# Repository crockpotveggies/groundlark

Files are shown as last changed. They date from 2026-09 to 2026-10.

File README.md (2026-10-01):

Groundlark — lark and seismic waveform

# Groundlark — open hardware for seismic and environmental monitoring

Groundlark is a family of hardware boards and companion software for seismic
and environmental monitoring. Each board has its own hardware directory, with
shared component libraries, interfaces and validation tools.

The family has **three products**: the Groundlark FPGA HAT, Skylark and
Burrowlark USB sensor heads. All share the sensor contracts, simulation tools and local workbench.

## Groundlark

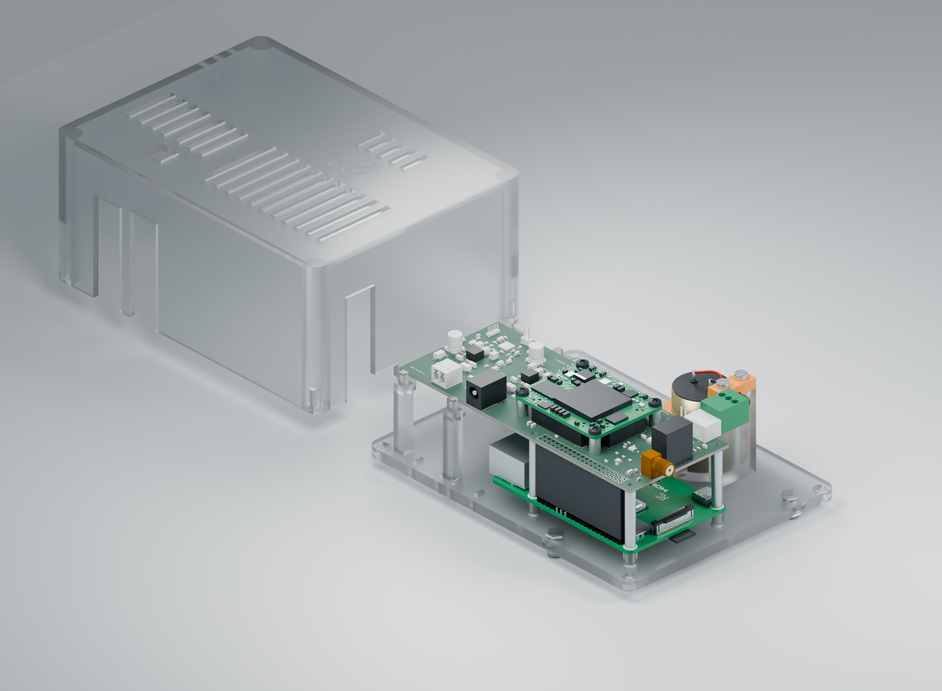
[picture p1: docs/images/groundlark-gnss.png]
Groundlark revised power and GNSS circuit: routed HAT with antenna current limiting, side SMA, Pi/Trenz stack and geophone


**Seismic monitoring on a Raspberry Pi.** The active
[Groundlark FPGA HAT](hw/groundlark-fpga-hat/README.md), model **DAQHAT-01**, is a
140 × 56 mm, six-layer FR-4 board with three XYZ LSM6DSO IMUs and an ADS122C04
input for an external Racotech geophone, plus a fitted DLVR infrasound sensor and u-blox MAX-M10S GNSS with a side-facing SMA antenna connector. The stack is **Pi → HAT → Trenz
Artix-7 200T FPGA**. Pi acquisition works independently of a configured FPGA.

The [internal FPGA link](docs/fpga-host-link.md) provides six QSPI wires, UART,
reset and switched Pi-driven JTAG. An SPI echo bitstream is implemented;
accelerated sensor processing and native quad transfers remain future work.
The FPGA uses a separate Nexys Video-compatible 12 V, center-positive adapter through J83 and an onboard 3.326 V converter. See the [power limits](docs/trenz-hat.md).

**Status:** active prototype. Physical power, fit, timing, noise and thermal
qualification remain pending. See the [stack assembly guide](docs/stack-assembly.md),
[JLCPCB instructions](docs/jlcpcb-assembly.md) and [bench procedure](docs/bench-procedure.md).
The JLCPCB package targets one assembled HAT; sourcing, placement and J1 fit
checks remain open. Fabrication packages stay local in ignored `hw/releases/`.

*R3 [prototype enclosure](hw/mechanical/daqhat-01-case/README.md), current
140 mm HAT CAD with GNSS/SMA, infrasound, TI Pi supervision and independent FPGA power, vendor Trenz components and a detailed
[Pi 4B model](hw/shared/models/raspberrypi4/README.md) by integrated-circuit / FreeCAD
community (CC BY 3.0). Clear PETG appearance, risers, geophone and wiring are approximate.
Physical fit remains unqualified. [Render provenance](docs/images/groundlark-gnss.json).*

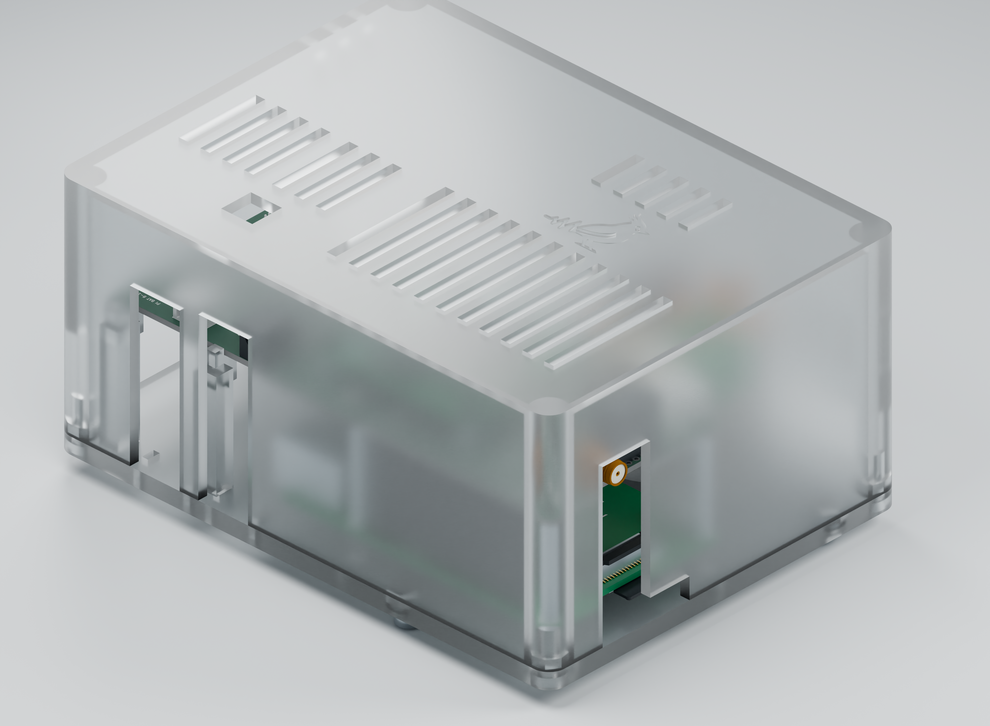
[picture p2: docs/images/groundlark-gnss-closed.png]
Groundlark enclosure with the side SMA accessible


[Closed enclosure render provenance](docs/images/groundlark-gnss-closed.json).
Measured gain/offset workflows and PCB probe access are in the
[calibration guide](docs/calibration.md). Seismic recordings support local
[miniSEED export](docs/miniseed.md).

## Skylark

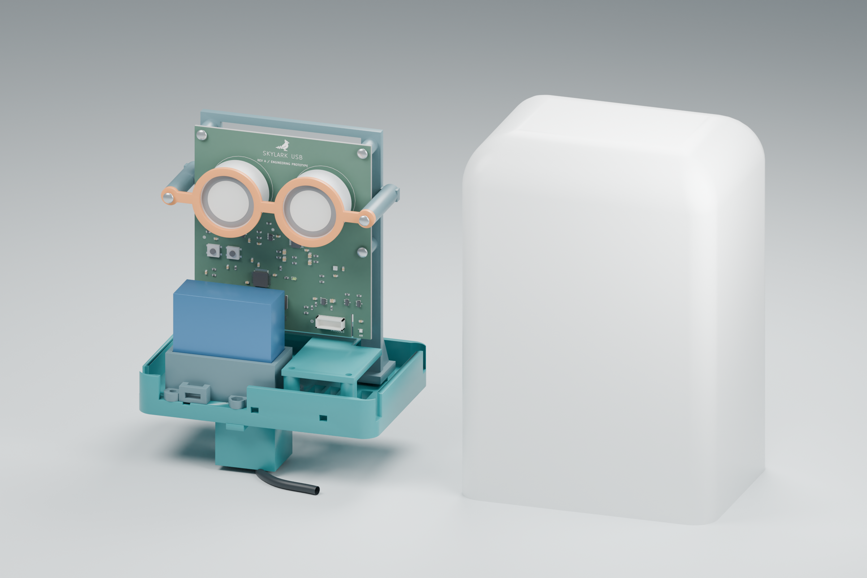
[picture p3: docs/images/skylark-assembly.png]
Skylark USB: populated vertical PCB and gas cells in the removable tray, with the white bell enclosure beside it


**Outdoor air-quality monitoring over USB.** [Skylark USB](hw/skylark-usb/README.md)
combines a vertical **90 × 100 mm PCB** with a removable sensor tray and a
**130 × 94 × 185 mm bell enclosure**.

- **Particles:** Plantower PMS5003, with separate downward-facing inlet and exhaust paths.
- **Gases:** socketed SGX-7SO2-AQ-20 sulfur dioxide and SGX-7H2S-AQ-25 hydrogen sulfide cells.
- **Weather:** SHT40 temperature/humidity and BMP390 barometric pressure.
- **Connection:** USB-C power and data through an STM32F072 microcontroller.
- **Housing:** printable bell, rear M4 keyhole mounts and a removable tray with
  separate PMS cradle and splash cover. Bottom ventilation is sheltered by a 25 mm skirt.

[Prototype firmware](sw/skylark/README.md) implements sensor acquisition and
USB streaming. The shared workbench includes Skylark simulation, recording/replay,
board-specific tests and an interactive 3D PCB. Gas data retains separate raw
working and auxiliary electrode counts; concentrations require calibration.

**Status:** Rev A PCB, Rev G enclosure and prototype firmware are implemented.
Physical fit, USB power behavior, analog performance, gas response and weather
resistance still require qualification. The ventilated enclosure has no assigned
IP rating. Follow the [PCB guide](hw/skylark-usb/README.md) and
[enclosure assembly instructions](hw/skylark-usb/mechanical/bell/README.md).

*Render: native PCB artwork and authored component models in the CAD-derived
tray, with the bell set beside it. Component bodies are dimension envelopes;
fasteners and cable dressing are illustrative. [Render provenance](docs/images/skylark-assembly.json).*

## Burrowlark

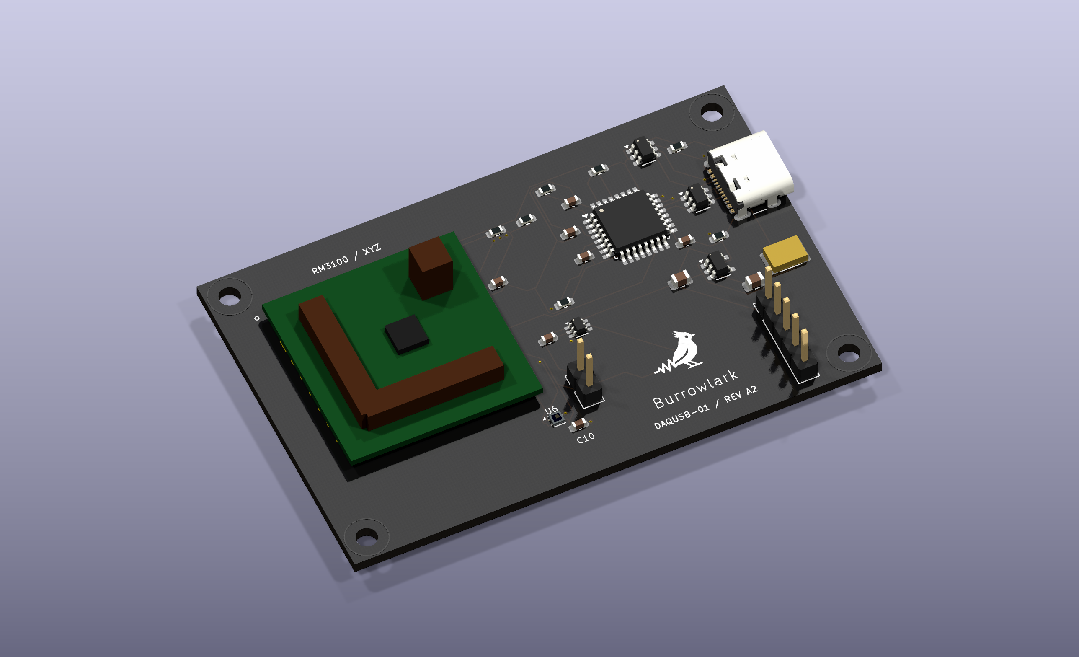
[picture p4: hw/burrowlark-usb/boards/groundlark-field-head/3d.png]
Burrowlark DAQUSB-01 Rev A2: USB-C PCB with PNI RM3100 XYZ magnetometer and SHT45 temperature/humidity


**Remote magnetic and enclosure-climate sensing over USB.**
[Burrowlark USB](hw/burrowlark-usb/README.md), model **DAQUSB-01**, carries an
RM3100 magnetometer and SHT45 temperature/humidity sensor. It connects to the Pi through USB-C for power and data.
The DLVR infrasound sensor is fitted on Groundlark DAQHAT-01.

**Status:** hardware design and workbench simulation are present; MCU firmware
and physical qualification remain pending. See the
[USB sensor-head guide](docs/usb-sensor-head.md) for interfaces and assembly details.

*Render: native 70 × 45 mm PCB with favicon, Burrowlark name and DAQUSB-01 / REV A2
silkscreen, RM3100 module and SHT45 U6/C10; the former infrasound
footprint and bypass capacitor are removed. Module, fuse and SHT45 bodies are simplified
dimensional envelopes. [Render provenance](hw/burrowlark-usb/boards/groundlark-field-head/render-provenance.json).*

## Sensor workbench

The dark-mode Python UI lets you switch between Groundlark, Skylark and
Burrowlark, with interactive 3D views, raw-data charts, stimulus/fault controls,
board-specific tests and recording/replay.
No hardware or Docker is required. Follow the
[beginner walkthrough](docs/sensor-workbench.md) to create your first signal.

```powershell
# Windows: set up once, then launch
./setup-ui.ps1 -Check
./ui.ps1
```

On Linux/macOS, use `sh ./setup-ui.sh --check`, then `sh ./ui.sh`.
Open **http://127.0.0.1:8080**. Tools and dependencies stay in ignored `.local/`.

Groundlark sensor workbench showing the external geophone and a simulated 2 Hz signal

This is an actual browser screenshot with simulated data. Select the geophone
can or its HAT input to highlight both and inspect the same ADC stream.
Use the **Board** selector for the FPGA HAT, Burrowlark or Skylark.
**Test selected board** runs the selected board’s checks; the HAT test covers all
six sensors over eight simulated seconds. IMU, ADC and GNSS use production Pi
drivers on modeled buses; infrasound uses a raw-response model pending its Pi
driver. Signal checks and recordings/results are downloadable.
The Groundlark GNSS panel also models disconnected or shorted antennas, lock
loss and recovery, and PPS loss independently.
The UI simulates and replays; physical acquisition uses the [Pi software](docs/sensor-software.md).
Live seismic capture stores raw geophone and IMU counts locally as
[miniSEED 3](docs/miniseed.md), with SSREC companions for diagnostics and replay.

## Project files and tests

| Directory | Contents |
| --- | --- |
| [hw/](hw/README.md) | Four product directories, shared component resources, hardware checks and SPICE. |
| [sw/](sw/README.md) | Pi acquisition, contracts, simulator, FPGA and remote firmware interfaces. |
| [docs/](docs/README.md) | Setup, hardware specifications, assembly, interfaces and testing instructions. |
| [environment/](docs/portable-lab.md) | Pinned Docker test environment and bounded cleanup tooling. |

For the full test environment, run `./lab.ps1 build` once, then `./lab.ps1 test`.
Use `./lab.ps1 test -Profile software` for sensor contracts, acquisition,
recording/replay and recovery. See the [portable lab guide](docs/portable-lab.md)
for Linux commands, test scope, five-run retention and cleanup.

Hardware sources: [DAQHAT-01 circuit](hw/groundlark-fpga-hat/elec/hat_trenz.ato),
[KiCad PCB](hw/groundlark-fpga-hat/boards/groundlark-daqhat-01/groundlark-daqhat-01.kicad_pcb),
[Burrowlark DAQUSB-01](hw/burrowlark-usb/boards/groundlark-field-head/groundlark-field-head.kicad_pcb), and
[Skylark USB](hw/skylark-usb/boards/skylark-usb/skylark-usb.kicad_pcb).
See [build instructions](docs/build.md) and [source references](docs/sources.md).

## License

Project-authored code, hardware designs and documentation use the [MIT License](LICENSE).
Third-party assets and dependencies retain their own licenses and attribution.

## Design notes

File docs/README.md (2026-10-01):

# Documentation

## Getting started

- [Sensor workbench](sensor-workbench.md): installation, first experiment, recordings and replay.
- [Sensor software](sensor-software.md): command-line simulation and Pi acquisition.
- [Stimulus scenarios](stimulus-models.md): saved inputs, waveforms and sensor-model limits.
- [Project layout](project-layout.md): where to find hardware, software and generated files.

## Hardware and assembly

- [DAQHAT-01 hardware](trenz-hat.md): sensors, Trenz module, power, connectors and fabrication stack.
- [Pi/FPGA host link](fpga-host-link.md): SPI/QSPI pins, UART, JTAG and bring-up.
- [Geophone input](geophone-input.md): Racotech connection, analog circuit and accelerometer axes.
- [Sensor bandwidth and timing](sensor-response.md): Groundlark and Skylark attenuation, sampling and qualification limits.
- [Power supplies](power-supplies.md): Pi-header and USB allocations, source-voltage restrictions and startup/suspend requirements.
- [Stack assembly](stack-assembly.md): Pi, HAT, FPGA, cooling, supports and geophone lead.
- [JLCPCB assembly](jlcpcb-assembly.md): upload files, selected parts, placement and manufacturing requirements.
- [Physical bench procedure](bench-procedure.md): power, fit, timing and noise measurements.
- [Validation and release limits](validation.md).
- [Burrowlark DAQUSB-01 USB sensor head](usb-sensor-head.md): magnetometer and firmware interface.

## Interfaces and reproducible builds

- [Sensor data contract](sensor-contract.md) and [schema tools](../sw/interfaces/README.md).
- [GNSS hardware](gnss-hardware.md): MAX-M10S, side SMA, antenna and power requirements.
- [GNSS timing](utc-timing.md): BCM24 PPS capture, recording-bound UTC correlation and timing qualification.
- [Hardware build](build.md), [portable tests](portable-lab.md) and [SPICE scope](../hw/shared/simulation/README.md).
- [Component and vendor references](sources.md).

The hardware is an engineering prototype. Modeled tests do not replace physical
power, fit, timing, thermal or noise qualification.

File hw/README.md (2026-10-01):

# Hardware

Each product has its own directory. Existing model names and atopile targets
remain stable so board identity does not depend on its directory name.

| Product | Model / outline | Build target | Status |
| --- | --- | --- | --- |
| [Groundlark FPGA HAT](groundlark-fpga-hat/README.md) | DAQHAT-01, 140 × 56 mm | `trenz_hat` | Active prototype; physical qualification pending. |
| [Burrowlark USB](burrowlark-usb/README.md) | DAQUSB-01, 70 × 45 mm | `field_head` | Hardware design present; firmware pending. |
| [Skylark USB](skylark-usb/README.md) | Rev A, 90 × 100 mm | `skylark` | Routed air-quality prototype, STM32 firmware and Rev G bell enclosure; physical qualification pending. |

## Product contents

- `elec/`: authored circuit and product-specific part definitions.
- `layout/placement.json`: placement metadata for that board.
- `layout/<target>/`: atopile connectivity layout and local library tables.
- `boards/<board>/`: routed native CAD, review schematics, BOMs, previews and validation evidence.
- `mechanical/` and `simulation/`: product-specific artifacts where applicable.

Skylark includes its circuit, routed PCB, review schematic, BOM and CAD renders.
Stack concept boards are visualization artifacts.

## Shared resources and tooling

[shared/](shared/README.md) holds common part definitions, KiCad libraries, models,
vendor/reference material and simulations used by multiple boards. Custom CAD
resource paths remain relative.

`tools/` and `tests/` retain the existing shared and cross-board checks.
`assembly/<product>/` holds procurement overrides; `releases/<product>/` is for
ignored local fabrication packages, which require explicit authorization to publish.
Disposable runs belong in `.lab/`; local dependencies belong in `.local/`.
Firmware and host software belong in `sw/`.

`ato.yaml` defines four implemented targets. Direct atopile commands target
`hw/` from the repository root and write authoring outputs.

Use the root portable lab for routine checks. See the [build guide](../docs/build.md),
[Trenz guide](../docs/trenz-hat.md) and [validation limits](../docs/validation.md)
before invoking the lower-level authoring tools.

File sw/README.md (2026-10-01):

# Software

The sensor HAT is driven by Pi software; it does not need separate MCU firmware.
The [acquisition software](../docs/sensor-software.md) supports sensors on the
DAQHAT-01 FPGA stack and runs without a configured FPGA.
The sensor contracts and Pi acquisition application are executable:

- [interfaces/](interfaces/README.md): Protobuf schemas, semantic validation and bounded USB framing.
- [pi/](pi/README.md): Pi device configuration, sensor drivers/adapters, acquisition,
  calibration and timestamps.
- [field-head/](field-head/README.md): microcontroller firmware for Burrowlark
  (DAQUSB-01), the remote USB-C magnetometer board.
- [skylark/](skylark/README.md): buildable STM32 USB air-quality firmware, native driver fault tests and shared v1 capture.
- [fpga/](fpga/README.md): Trenz pin/connectivity qualification and minimal test
  bitstreams; accelerator implementation is deferred.
- [tests/](tests/README.md): portable replay, fault injection and host integration.
- [ui/](ui/README.md): Python/NiceGUI local sensor workbench, board explorer,
  stimulus controls and recording/replay.

Run `./lab.ps1 test -Profile software` after rebuilding the portable image.
This checks schemas, compatibility, acquisition/replay, modeled bus drivers,
USB streams and recovery from injected faults. See the
[software run guide](../docs/sensor-software.md). Burrowlark and Skylark prototype firmware have native C and ARM checks; physical qualification remains pending. Tests do not emulate
Pi/MCU instructions or enumerate a USB sensor head.

## Pi power policy

The optional TI supervisor has a disabled [configuration template](pi/deploy/power-policy.example.json)
and a tested [validator](pi/groundlark/power_config.py). Battery thresholds are
intentionally unset. [Prototype MSPM0 firmware](supervisor/README.md), validated
build-time policy generation and Pi kernel shutdown/acknowledgement configuration
are implemented. The default firmware keeps RUN off; loading the JSON template
does not change hardware power. Battery selection and physical qualification remain pending.
See the [power operating specification](../docs/power-supplies.md#pi-supervisor-and-battery-input).

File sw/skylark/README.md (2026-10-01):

# Skylark USB firmware

Prototype firmware for the **STM32F072CBT6** on the current Skylark Rev A PCB.
The ARM image builds and the production C sensor drivers, encoder and boot
journal run in native fault tests. Physical USB enumeration, suspend current,
sensor timing, analog settling and calibration still require a populated board.

## Build and test

From the repository root:

```powershell
./lab.ps1 build
./lab.ps1 unit
./lab.ps1 test -Profile software
```

Linux/macOS: use `sh ./lab.sh build`, `sh ./lab.sh unit`, and
`sh ./lab.sh test --profile software`. The shared software profile builds the
firmware, checks wire compatibility, and compiles/runs the actual C drivers with
injected I²C/UART failures. It also exercises queue overflow, reconnects, warmup,
conversion-counter loss, and interrupted flash writes/erases.

The lab uses Debian ARM GCC 12.2.1 and libopencm3 commit
`2da12dc96e0b9e42a3332348dd9b02a0a17981f8`, fetched and SHA-256 verified by
[install_skylark.py](../../environment/install_skylark.py). Complete upstream
sources and licenses remain under `/opt/skylark/libopencm3` in the image.
The application is MIT; libopencm3 retains its LGPL-3.0-or-later license.
Preserve corresponding sources and license notices when distributing firmware.

For a direct Linux build with that library and an ARM GCC toolchain:

```sh
make -C sw/skylark/firmware LIBOPENCM3=/absolute/path/to/libopencm3 \
  EXTRA_CFLAGS=-isystem/usr/include/newlib
```

Outputs are ignored `sw/skylark/build/skylark.elf` and `skylark.bin`.
The portable profile instead builds under `sw/build/skylark-arm/` in its
disposable workspace and retains ELF/BIN/map plus size and SHA-256 metadata in
`.lab/runs/<run-id>/results/sw/build/skylark-arm/`. The link reserves at least 4 KiB for stack; no heap or
RTOS is used. Physical stack watermarking remains part of bring-up.

## Program a prototype

Use J3 SWD with a 3.3 V compatible ST-Link and the STM32F0 target profile.
The image starts at `0x08000000`; the last **4 KiB at 0x0801F000–0x0801FFFF**
store a two-page boot counter. Program/verify only image pages. **Do not mass
erase or overwrite the journal during updates:** reusing a device/boot identity
breaks recording ordering. A failed or exhausted counter stops acquisition.
SW1 resets the MCU; SW2 selects the STM32 ROM bootloader when held during reset.
The normal acquisition path needs neither button.

Default USB **1209:0001** is the pid.codes identifier reserved for
[private in-house testing](https://pid.codes/1209/0001/). Before distributing
devices, build with an allocated VID/PID via
`EXTRA_CFLAGS='-DSK_USB_VID=... -DSK_USB_PID=... -isystem/usr/include/newlib'`.
The serial string is the MCU's 96-bit unique ID. The USB device requests 500 mA.

## Acquisition

USB configuration starts sensor power and acquisition. CDC DTR opens the data
session; closing the port leaves the cells conditioned and continues acquisition
without buffering disconnected samples. Reopening announces a new configuration
revision with sequence continuity and does not restart conditioning.
USB reset, unconfiguration or suspend clamps the electrodes and removes
analog/PMS power. Restoring USB power authorization repeats sensor setup and warmup.
The MCU reduces its clock to 12 MHz in suspend and disables the ADC/UART/I²C peripherals;
the actual total suspend current and USB compliance are **not measured**.

| Sensor | Firmware behavior |
| --- | --- |
| ADS122C04, I²C 0x40 | AIN0/1 = SO₂ working/auxiliary; AIN2/3 = H₂S working/auxiliary. Gain 1, PGA bypass, external 2.5 V reference, normal 330 SPS single-shot conversions. Four slots, 8 ms apart; 32 ms per channel. Readback, inverted-data integrity and conversion counter checked. |
| SHT40, I²C 0x44 | Serial probe, high-precision measurement approximately every second, CRC on both raw words; heater off. Conversion waits are nonblocking. |
| BMP388, I²C 0x76 | Chip ID 0x50/readback, pressure ×8 and temperature ×2 oversampling, 3.125 Hz normal mode; latest ready sample every second. Six raw bytes plus 21 factory trim bytes retained. |
| PMS5003, USART2 | 9600 8N1; complete 32-byte active-mode frames with checksum/error-byte checking. Latest fresh frame published every second. Rail-fault/low-VBUS detection disables power. |

On startup, analog rails settle for 150 ms while electrodes remain clamped.
Gas samples are **missing for 60 seconds**, PMS samples for **30 seconds**.
These are prototype policies, not measured cell stabilization guarantees.
Keep raw working and auxiliary values separate. ADC volts = counts × 2.5 / 2²³;
ppm conversion, zero/temperature compensation and detection thresholds require
cell-specific calibration, polarity checks and environmental qualification.

The gas ADC scheduler advances one channel per completed service slot. A delayed
loop extends the schedule and exposes sequence gaps; it cannot start a burst of
conversions without waiting for them. Each new conversion receives at least
five integer-millisecond ticks after START, exceeding the 3.13 ms slow-clock conversion time. The 8 ms schedule includes I²C transfer time. This does not make WE/AE simultaneous. See
[sensor bandwidth and timing](../../docs/sensor-response.md) for attenuation,
aliasing and the remaining physical response limits.

Three I/O failures latch the affected sensor until USB power is reset. Closing
and reopening the serial port does not clear the latch or disturb electrode bias.
All four gas streams share the ADC's fault state; other sensors continue.
Not-ready, invalid checksum, stale PMS data, warmup and unknown conversion loss
never become zero measurements. The eight-frame transmit queue drops newest
data under backpressure. Sequence gaps remain visible; loss counts are unknown.
The firmware never resets the ADC solely because its counter skipped.

The MCU supply-monitor ADC has bounded calibration, enable, conversion and
disable waits. Calibration includes the ES0223 settling workaround. Timeout or
overrun disables the monitor until re-enabled; an unavailable monitor prevents
PMS power authorization. A late result cannot be reused as a different channel.
The I²C master clears spurious BERR as specified by ES0223, while NACK and
arbitration loss remain failures even when a completion flag is also set.
The bus remains at 100 kHz with an 8 MHz kernel clock. USB/APB remains at
least 12 MHz during suspend polling and resume. Unconnected MCU pins have
their digital input buffers disabled. See [source budgets](../../docs/power-supplies.md)
for supply-voltage restrictions and the unmeasured suspend-current requirement.

## Capture and replay

The firmware uses the existing [v1 sensor contract](../../docs/sensor-contract.md):
COBS, CRC-32, protobuf identity/configuration/batches/status, board ID 3.
No ASCII console, command protocol or calibrated gas values are emitted.
Generate the current descriptor as described in the
[software guide](../../docs/sensor-software.md), then on Linux:

```sh
python sw/tools/sensor.py usb --board skylark --usb /dev/ttyACM0 \
  --seconds 120 --output sw/build/skylark-field.ssrec
python sw/tools/sensor.py replay sw/build/skylark-field.ssrec
python sw/tools/sensor.py simulate --board skylark --seconds 8 \
  --output sw/build/skylark-sim.ssrec
```

Prefer the actual `/dev/serial/by-id/...` path when several USB devices exist.
The same bounded receiver, validation and recording format serve both USB boards.
Open captures in the existing workbench; choose **Skylark USB** for simulation,
or **Test selected board** for an ideal-stimulus acquisition/replay check.
That UI test does not run MCU instructions. Native C driver tests and ARM linking
are in the portable software profile. Burrowlark firmware remains separate.

## Source references

- [TI ADS122C04 datasheet](https://www.ti.com/lit/ds/symlink/ads122c04.pdf), register map and data integrity.
- [Sensirion SHT4x datasheet](https://sensirion.com/resource/datasheet/sht4x), commands and CRC.
- [Bosch BMP388 datasheet](https://www.bosch-sensortec.com/media/boschsensortec/downloads/datasheets/bst-bmp388-ds001.pdf), register profile and compensation.
- [libopencm3](https://github.com/libopencm3/libopencm3), STM32 peripherals and USB CDC support.
- [STM32F072 ES0223](https://www.st.com/resource/en/errata_sheet/es0223-stm32f072x8xb-device-errata-stmicroelectronics.pdf), ADC calibration, I²C master BERR and USB/APB limits.
- [Hardware pin/power requirements](../../hw/skylark-usb/README.md), including the SGX bias assumption and outstanding physical checks.

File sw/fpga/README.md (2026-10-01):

# Trenz FPGA integration

DAQHAT-01 reserves six SPI/QSPI signals and retains UART/reset. Four data-link
wires switch to dedicated JTAG for programming directly from the Pi. See the
[host-link guide](../../docs/fpga-host-link.md) and
[pin contract](../../docs/trenz-gpio-breakout.csv).

The initial Pi 4 transport is ordinary SPI6, with DQ2/DQ3 unused. Quad needs a
separate host engine and reviewed slave RTL. Keep sensor acquisition independent
of FPGA configuration. An existing Nexys
Video bitstream is not a Trenz port.

`rtl/daqhat_01_link.sv` is a single-clock 50 MHz SPI echo mailbox with length/CRC/sequence
checks and one-frame backpressure. Run `python3 sw/fpga/test.py` with the pinned
Icarus installation, or use the full/software lab profile. `build.tcl` implements
it for XC7A200T-FBG484-1 in Vivado; run from ignored `.local/` storage. The
[recorded implementation evidence](verification/result.json) includes timing,
CDC, DRC and source hashes. Physical Pi/Trenz programming remains untested.

`cosim.py` connects the production Python client to simulated RTL pins, covering
all 193 payload sizes, sequence wrap, 20 clock phases and 491 malformed/reset cases.
`verify_reports.py` rejects stale source/report hashes, missing timing coverage,
negative slack and reported CDC/DRC findings. After a successful Vivado build,
record it with `python sw/fpga/verify_reports.py --record /path/to/output`, then
run the portable tests. The portable evidence check verifies those recorded
results; it does not run Vivado inside Docker.

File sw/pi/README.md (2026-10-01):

# Raspberry Pi software

Use `calibration-observe` and `calibration-fit` for measured static gain/offset. The [calibration guide](../../docs/calibration.md) covers fixtures, templates, evidence and instrument binding.

Executable acquisition, calibration, bounded recording/replay, Linux adapters
and deterministic simulation are in `groundlark/`. No configured FPGA is needed.
See the [run guide and recovery policy](../../docs/sensor-software.md).
Live HAT capture writes local [miniSEED 3 seismic files](../../docs/miniseed.md)
alongside SSREC diagnostics. Counts remain raw; Pi system timing is marked unverified.
Use the [stimulus guide](../../docs/stimulus-models.md) for motion/field/pressure
waveforms, GNSS trajectories and timed faults. Example: add
`--scenario sw/pi/profiles/stimulus-demo.json` to the simulation command.

Separate pure processing/protocol logic from Linux I2C/SPI/UART/USB adapters so
the same application can run against recorded samples and fault-injecting fakes.
Use the [DAQHAT-01 sensor/carrier design](../../docs/trenz-hat.md) and
[USB interface contract](../../docs/usb-sensor-head.md).

Run `./lab.ps1 test -Profile software` for the complete portable demo and tests.
Live adapters cover LSM6DSO, legacy SCL3300, ADS122C04, DLVR-F50D and MAX-M10S.
Bus logic has modeled-response tests. The geophone has a dedicated DRDY worker
with bounded buffering and explicit loss reporting.
[Pi 4 deployment](deploy/README.md), IRQ-assisted FIFO acquisition and PPS
edge recording are implemented. [UTC capture/correlation](../../docs/utc-timing.md)
and [bench report tools](../../docs/bench-procedure.md) are available; physical
timing bounds and validation remain bring-up work. USB ingestion expects a v1 producer;
both STM32 heads have prototype firmware with native fault tests and ARM builds.

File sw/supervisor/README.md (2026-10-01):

# DAQHAT-01 Pi power supervisor

`firmware/` targets MSPM0L1106TRHBR. The default image leaves RUN off because
the battery/controller policy is disabled. JP130 remains a bench override;
automatic operation requires removing its shunt.

The production C state machine checks voltage hysteresis, confirmation intervals,
minimum off time and halt acknowledgement. Invalid ADC readings request orderly
shutdown while running and prevent restart while off. Three shutdown timeouts
latch the controller off until reset. An independent watchdog resets a stalled
firmware loop. MCU reset returns RUN to its externally pulled-down state.

PA3 drives RUN, PA4 requests shutdown through Q130, PA5 reads ACK_N through Q131,
and PA27/ADC0.0 measures the R135/R136 divider. The nominal 2.5 V ADC conversion
is not calibrated. SWD remains available. The default image does not write factory
BCR/BSL configuration memory or provision a battery policy.

Build and native fault tests run in `./lab.ps1 test -Profile software`.
The TI SDK is pinned by `environment/install_supervisor.py`; its BSD notices
remain in the toolchain sources. Target linking and native tests are software
evidence only. ADC accuracy, voltage transients, watchdog timing and shutdown
behavior require the actual board.

For a later supervised bench build, start from
`sw/pi/deploy/power-policy.example.json`, select the protected battery/controller,
then generate a separate policy header:

```sh
python sw/supervisor/configure.py selected-policy.json /tmp/selected-policy.h
make -C sw/supervisor/firmware EXTRA_CFLAGS='-DPOLICY_HEADER=\"/tmp/selected-policy.h\"'
```

Every enabled policy must pass both the Python and C validators. Selecting a policy
does not qualify it. Flash over SWD only during physical bring-up.

Pi handshake settings are in `sw/pi/deploy/supervisor-boot.cfg`. BCM6 generates
a power-key shutdown request; BCM13 is asserted by the kernel poweroff path,
after filesystem shutdown. A stopped acquisition service never asserts halt.
Install the logind drop-in during that bring-up. The `gpio-poweroff` overlay
requires working external power removal; do not enable it with the default
disabled supervisor image or with JP130 bypassing the switch.

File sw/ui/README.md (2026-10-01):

# Python sensor workbench

From the repository root, run `./setup-ui.ps1 -Check`, then `./ui.ps1`.
On Linux/macOS, use `sh ./setup-ui.sh --check`, then `sh ./ui.sh`.
Open `http://127.0.0.1:8080`; Ctrl+C in the terminal stops the server.
See the [beginner walkthrough](../../docs/sensor-workbench.md).

The same app serves `/station` for persistent simulation or live acquisition.
Set the UI service's `GROUNDLARK_STATION_TOKEN` to match the local station service;
the browser never receives that API credential. Use the
[deployment guide](../pi/deploy/README.md) for station setup, storage, LAN login
and source profiles. Closing `/station` leaves capture running. Pause/resume,
completed-recording downloads and validated configuration editing are local.

Rerun `./ui.ps1 -Check` / `sh ./ui.sh --check` for the HTTP and scene tests.
The full acquisition/controller tests use the portable software profile.

- `main.py`: Python page construction, charts, board scene and user callbacks.
- `geophone_scene.py`: selectable external geophone and illustrative leads.
- `test_geophone_scene.py`: geometry and shared ADC/can selection regression.
- `test_skylark_scene.py`: exported cell dimensions, position and shared working/auxiliary selection.
- `style.css`: visual styling and responsive layout; dark by default.
- `pyproject.toml`, `uv.lock`: isolated, reproducible optional UI environment.
- `check.py`: page-construction/asset-delivery smoke check.
- `assets/`: checked display assets and provenance, separate from editable CAD.
- `build_wordmark.py`: compose the original favicon and outlined UI lettering
  for the shared README/header asset; see `assets/README.md` for regeneration.
- [workbench.py](../pi/groundlark/workbench.py): bounded framework-independent
  simulation/recording/replay controller.
- [test_workbench.py](../tests/test_workbench.py): controller regression tests.
- [hat_signals.py](../pi/groundlark/hat_signals.py): measured HAT signal regression
  behind the **Test selected board** button, using production drivers on modeled buses.

The UI is authored in Python. NiceGUI supplies bundled browser components based
on Vue, Quasar, Three.js and ECharts. There is no custom JavaScript application,
Node dependency install, npm build, or separate frontend server in this project.

The board selector switches experiments and models between the FPGA HAT,
Burrowlark and Skylark. `skylark_scene.py` adds
selectable gas/climate/PM targets to the native PCB/package GLB.
`build_skylark_model.py` is build-only tooling; its dependencies are separate
from the locked UI environment. See [asset provenance](assets/README.md).

Burrowlark includes RM3100 and SHT45 sensor 17. Select its enclosure-climate
channel to adjust temperature and humidity, inject faults and inspect both plots.
**Test selected board** verifies independent faults, recovery and recording/replay.
`build_burrowlark_model.py` merges the native KiCad export with the authored
PNI/PTC/SHT45 envelopes; see `assets/README.md` for regeneration.

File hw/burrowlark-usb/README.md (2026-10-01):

# Burrowlark USB — DAQUSB-01

Burrowlark is the separate 70 × 45 mm USB-C magnetometer and enclosure-climate
sensor head. It uses the PNI 14190 RM3100 XYZ module; U3/C5 and their pressure-sensor
branches are removed. The DLVR pressure sensor is on DAQHAT-01. Prototype
[USB-head firmware](../../sw/field-head/README.md) has native and ARM checks;
physical qualification remains pending.

Burrowlark DAQUSB-01 Rev A2 with favicon, RM3100 and SHT45

Native PCB render with the Groundlark favicon, Burrowlark name and
`DAQUSB-01 / REV A2` front silkscreen. The existing A2 board revision is retained.
Module, fuse and SHT45 bodies are simplified envelopes; see
[render provenance](boards/groundlark-field-head/render-provenance.json).

- [Electrical source](elec/field_head.ato)
- [Placement inputs](layout/placement.json)
- [Routed KiCad project](boards/groundlark-field-head/groundlark-field-head.kicad_pro)
- [Assembly and interface guide](../../docs/usb-sensor-head.md)
- [Firmware directory](../../sw/field-head/)

Build target: `field_head` in [hw/ato.yaml](../ato.yaml). Existing CAD filenames
and the DAQUSB-01 model identifier are preserved.

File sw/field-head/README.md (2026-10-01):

# Burrowlark DAQUSB-01 firmware

Prototype STM32F042K6 firmware implements RM3100 magnetic and SHT45
temperature/humidity acquisition, USB CDC framing and reconnect handshakes.
The authoritative interface is the existing
[Burrowlark circuit and firmware contract](../../docs/usb-sensor-head.md), with
messages and framing in the [sensor data contract](../../docs/sensor-contract.md).
The bounded encoder uses no heap. The ARM build reserves two 1 KiB boot-journal
pages and at least 2 KiB of stack; the shared software profile checks the link.

Actual enumeration, sensor behavior, USB suspend current and physical validation are pending.
This firmware is separate from the Pi software that drives the accelerometer HAT.

The SHT45 profile uses address 0x44, heater-off high precision (0xFD), a 9 ms
conversion wait and one six-byte CRC-checked raw frame per second. Publish
sensor 17 under the USB-head identity using MCU timing. The Python injected-bus
reference is `sw/pi/groundlark/burrowlark.py`; the browser simulation exercises
it. Native C tests independently decode the target encoder's output and inject
I2C failures, CRC faults, DTR reconnects, suspend and backpressure.

Run `./lab.ps1 test -Profile software` (or `./lab.sh test --profile software`).
Firmware sources are in `firmware/`; binaries are retained in the bounded lab.
The default USB VID/PID is a private testing placeholder, not an allocated
product identity. Do not distribute it as a production USB device.

RM3100 uses cycle count 200, TMRC 0x96 and 10 Hz publication. Its physical
conversion loss remains unknown. Failed reads emit missing data; three consecutive
faults latch that sensor until the sensor supply is cycled. USB configuration
controls sensor power; suspend/reset turns it off. An independent watchdog
resets a stalled loop. Preserve the boot-journal pages when updating firmware.

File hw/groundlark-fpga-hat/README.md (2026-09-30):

# Groundlark FPGA HAT — DAQHAT-01

Underside TP90–TP93 provide passive calibration probe access; see the [bench calibration guide](../../docs/calibration.md). No additional GPIO or enclosure opening is required.

The active 140 × 56 mm, six-layer Trenz carrier combines three XYZ IMUs and
an ADS122C04 input for an external Racotech geophone, plus a fitted DLVR-F50D
infrasound pressure sensor on I2C1 (0x28). The stack is Raspberry Pi,
DAQHAT-01, then Trenz TE0712-03-81I36-A. Physical qualification remains pending.
J90 uses a horizontal Phoenix 1803280 header with the existing 1803581 cable
plug. Pin order remains positive, negative, shield.

MAX-M10S GNSS uses Pi I²C1 and BCM24 PPS, with a side-facing SMA and a
TPS2553 antenna fault limiter. ISO1640 side 2 faces the Pi/GNSS bus. J130 feeds
the separate MSPM0L1106 supervisor and 5.115 V Pi supply; battery policy and
MCU firmware remain pending. See [GNSS setup](../../docs/gnss-hardware.md).

J83 takes a Nexys Video-compatible 12 V, center-positive 5.5/2.1 mm adapter
rated at least 3 A. It faces the opposite edge from the geophone. U80 supplies
the FPGA independently of the Pi, with a 3 A output allocation; SW80 turns this
supply off/on. The first 25 mm of the extension contains FPGA input protection and conversion. Check the documented voltage, thermal and enclosure limits before
building; the supply remains an unqualified prototype.

- [Electrical source](elec/hat_trenz.ato)
- [Placement inputs](layout/placement.json)
- [Routed KiCad project](boards/groundlark-daqhat-01/groundlark-daqhat-01.kicad_pro)
- [Native routing snapshot](boards/groundlark-daqhat-01/groundlark-daqhat-01.ses)
- [Hardware and power specifications](../../docs/trenz-hat.md)
- [Pi and external source budgets](../../docs/power-supplies.md)
- [Sensor bandwidth and timing](../../docs/sensor-response.md)
- [Assembly instructions](../../docs/stack-assembly.md)

Build target: `trenz_hat` in [hw/ato.yaml](../ato.yaml). Use the root portable lab
for validation. `simulation/` contains bounded supporting-circuit models;
`mechanical/` retains earlier mechanical artifacts with their recorded status.
FPGA sources remain under [sw/fpga/](../../sw/fpga/README.md).

Assembly uses an 8.5 mm JLCPCB socket, two external GPIO risers and measured
supports (28.06 mm nominal Pi gap). Sensor supply and bias returns have local
ground stitches. Procurement accepts in-stock PCB selections with component
MOQ 1; see [JLCPCB assembly](../../docs/jlcpcb-assembly.md).

Use the [R3 enclosure](../mechanical/daqhat-01-case/README.md) for the 140 × 56 mm
board. It adds power-wing supports, a rear DC opening opposite the geophone and
switch access. First-print fit and thermal qualification remain pending.

## Pi power supervisor

J130 accepts **8–18 V DC** from an externally protected battery/controller.
U130 is TI MSPM0L1105TRHBR; U131 powers it continuously while U132/U133 supply
and disconnect the Pi through header pins 2/4. The combined Pi/HAT allocation
is 3 A at nominal 5.149 V, for the Pi 4 stack. Do not simultaneously power the
Pi through USB-C. Keep J83's separate 12 V FPGA input independent.

Battery thresholds and delays are configurable placeholders, shipped disabled
in [power-policy.example.json](../../sw/pi/deploy/power-policy.example.json).
Target MCU firmware and physical power qualification remain pending. An
unprogrammed MCU leaves the Pi off; fitting the JP130 shunt provides manual
bench operation. Remove it before automatic supervision. See the
[operating specification](../../docs/power-supplies.md#pi-supervisor-and-battery-input).

## GNSS timing

U21 is a MAX-M10S-00B on Pi I2C1 (0x42); BCM24/header 18 captures PPS.
J140 is a side-facing SMA for a 3.3 V active antenna drawing at most 20 mA.
The 140 x 56 mm outline and independent FPGA power remain unchanged. Use the
updated R3 enclosure with its +X antenna access slot. See [antenna setup](../../docs/gnss-hardware.md)
and [timing capture/correlation](../../docs/utc-timing.md). Browser tests cover
modeled lock/PPS loss and recording/replay; physical millisecond alignment remains unqualified.

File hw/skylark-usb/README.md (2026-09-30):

# Skylark USB — Rev A

Skylark is the Groundlark project's outdoor air-quality accessory. Its **90 × 100 mm,
four-layer PCB** mounts vertically inside a ventilated, downward-open hood. Two
removable gas cells face the sheltered air space. A separate PMS5003 sits beside
the board, with its sampling face toward the bottom grille.

The front silkscreen carries the 7 mm Groundlark favicon above the Skylark title.

The atopile circuit, routed KiCad board, review schematic and BOM are implemented.
This is an **engineering prototype**, with [STM32 firmware](../../sw/skylark/README.md)
and shared simulation/tests implemented. Calibration and physical
qualification remain pending; it is not a fabrication release or a validated
volcanic warning instrument. No camera, Pi HAT or separate sensor daughterboard is included.

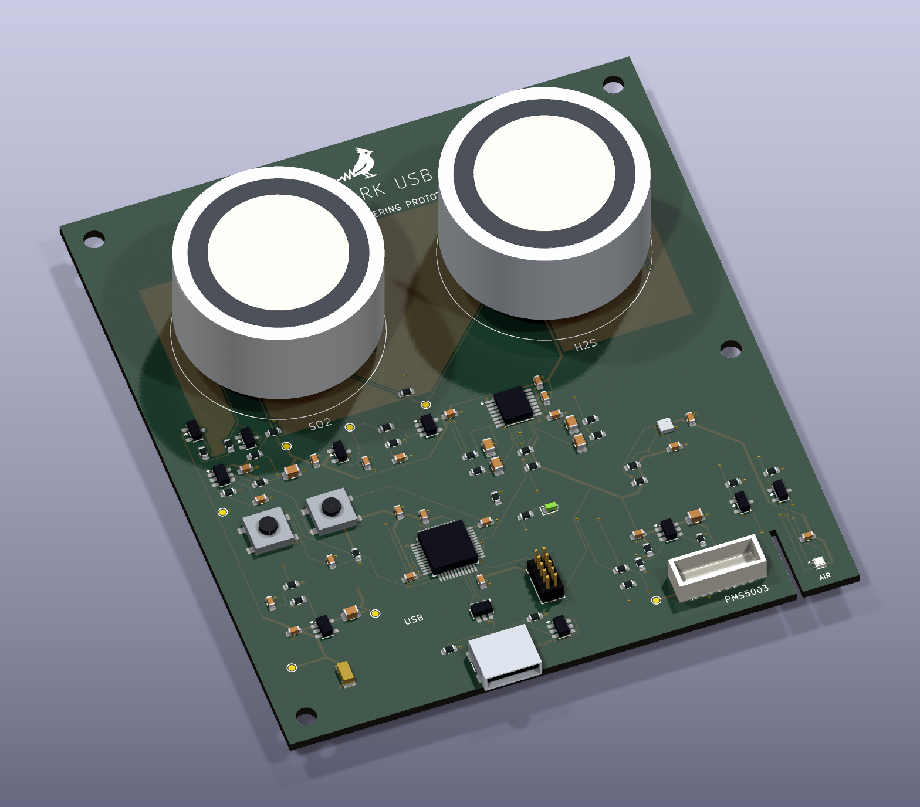
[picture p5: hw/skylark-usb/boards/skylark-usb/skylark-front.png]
Skylark native PCB render


## Hardware

| Function | Implementation |
| --- | --- |
| USB | USB-C, USB 2.0 full speed; STM32F072CBT6 with internal USB clock |
| SO₂ | SGX-7SO2-AQ-20, separate working/auxiliary TIAs, 100 kΩ feedback |
| H₂S | SGX-7H2S-AQ-25, separate working/auxiliary TIAs, 20 kΩ feedback |
| Gas conversion | ADS122C04, external REF3025 reference, four independent ADC inputs |
| Analog circuits | OPA387/OPA2387, switched analog supply, buffered 1.25 V electrode reference, compensated potentiostats, power-off electrode clamps |
| Particles | External PMS5003; protected switched 5 V supply, UART, sleep/reset control |
| Temperature/humidity | Filtered SHT40-AD1F-R2, I²C 0x44, on a slotted PCB finger near the lower ventilation |
| Pressure | BMP388, I²C 0x76 |
| Debug/service | 10-pin 1.27 mm SWD, reset/boot buttons, status LED and seven rail test pads |

Gas channels use 20 Ω electrode loads and 0.1%, 25 ppm/K thin-film gain resistors.
SO₂ feedback is 100 kΩ/100 nF; H₂S feedback is 20 kΩ/500 nF (five parallel
100 nF capacitors). Feedback and potentiostat compensation use C0G dielectric
to avoid the piezoelectric behavior of high-permittivity ceramic capacitors.
Each ADC input has a 10 kΩ/10 µF filter placed beside the ADC. Both gases have
a nominal 15.9 Hz feedback pole and a 1.59 Hz output pole. Together they attenuate a 50 Hz input signal
by about 40.3 dB before the ADC's digital filtering. These calculations omit cell
impedance, capacitor bias/temperature effects and amplifier noise gain; they
do not establish loop stability or a noise floor. Preserve matching WE/AE filters.

OPA387/OPA2387 specifies 177 nV peak-to-peak input noise over 0.1–10 Hz. Short,
via-free summing traces, local feedback and bypass returns reduce avoidable
pickup. The ADS122C04's typical ±5 nA bypass-mode input current can produce
about ±50 µV across 10 kΩ; this is a typical error estimate, not a guaranteed
bound. Measure channel offset and its drift, and retain calibration metadata.

Both outer faces have guard copper driven from the 1.25 V reference through
100 Ω R75. Exposed guard arcs surround the working, reference and auxiliary
socket pads; gaps allow signal traces to exit. Cleanliness remains essential:
4 nA of parasitic current mimics 10 ppb SO₂ at nominal sensitivity. Qualify
residual leakage after assembly, cleaning and coating, including humid soak
and fan-on/fan-off tests. Mask and coating alone do not establish that limit.

Both reference and working electrodes are nominally at 1.25 V;
this is a **zero-bias assumption**. SGX's public AQ datasheets do not unambiguously
specify bias for both exact variants. Obtain SGX confirmation before releasing
the circuit for fabrication. The manufacturer cell drawing is a bottom view;
the PCB socket pattern explicitly mirrors it.

Nominal sensitivity is 40 mV/ppm for SO₂ and 34 mV/ppm for H₂S. At the published
maximum sensitivity, full-scale gas excursions are approximately 1.00 V and
1.05 V around 1.25 V, respectively. These are headroom calculations, not detection
limits. Preserve raw WE and AE readings; compensation coefficients and baseline
calibration must come from measurements for each cell. A 24-bit ADC does not
establish ppb-level system accuracy.

## Assembly and installation

The [Skylark procurement registry](../assembly/skylark-usb/jlcpcb-parts.json)
covers all 119 PCB assembly placements in 37 exact manufacturer/catalog groups,
with dated stock observations in the registry. The current assembly uses
HRO TYPE-C-31-M-12 / C165948, Yageo RC0603FR-0782KL / C137678 and Bosch
BMP388 / C779278. These replacements were available without preorder, with a
minimum quantity of one, on 2026-09-28 UTC. Public stock is not reserved stock.
C2 retains its documented 16 V Murata 4.7 µF procurement substitution.

The [assembly guide](../assembly/skylark-usb/README.md) describes the read-only
Gerber/BOM/CPL exporter and manual parts. All 119 placements pass the numbered
supplier-pad fit, including explicit bottom-side handling. The HRO footprint
uses the manufacturer's 2020-12-08 drawing, shared power lands and plated shell
slots. Gas cells, eight sockets and the PMS5003 harness are assembled separately.
Recheck stock and both sides of the actual order preview before purchasing.

- Order JLCPCB's standard **1.6 mm, four-layer FR-4, JLC04161H-7628** stack:
  1 oz outer copper and 0.5 oz inner copper, with both inner layers assigned to
  ground. The recorded dielectric thicknesses are 0.2104 / 1.065 / 0.2104 mm.
  Use ENIG and conventional tented **0.60/0.30 mm through-vias** outside SMT pads.
  Minimum track/clearance is 0.15 mm. This design does not require HDI, blind or
  buried vias, filled/capped vias, or custom lamination. The stack comes from
  [JLCPCB's stock table](https://jlcpcb.com/impedance); USB signal integrity still
  requires a physical check. The selection does not imply an impedance guarantee.
- Fit **eight Mill-Max 0322-0-15-15-34-27-10-0 sockets** before inserting the cells.
  Finished socket holes are 2.35 mm nominal. The contact range covers the SGX
  1.00 ± 0.15 mm pins. Do not solder the gas cells directly. Check actual insertion
  and retention using purchased parts; provide a removable enclosure retainer.
- Gas-cell bodies are Ø31.5 × 15.5 mm. With the socket rim 4.88 mm above the PCB
  seating surface (including its 0.81 mm flange), allow at least 20.38 mm on the cell side, plus assembly tolerance and airflow
  clearance. The centers are 42 mm apart. Keep sensor faces clear.
- Four 3.2 mm mounting holes are at (4,4), (86,4), (4,96), (86,55) mm from the
  upper-left outline corner. USB and the temperature-sensor finger face down.
  The PMS5003 needs its own cradle and cable restraint.
- J2 is a **JST GH 8-pin board connector**. A harness must map its numbered pins
  to the PMS5003; do not assume an arbitrary supplied PMS cable mates with this
  header or preserves wire order.
- Clean and dry the PCB before installing cells. Conformal coating must exclude
  gas-cell faces and socket contacts, the SHT40 filter, BMP388 pressure port,
  connectors, buttons and service pads. Follow manufacturer assembly instructions;
  do not wash the installed humidity sensor or seal its filter.
- The hood provides rain shielding while admitting ambient air. Coating is an
  additional protection measure, not a waterproof enclosure. Avoid trapped water,
  direct spray, insects and condensation. Keep the PMS exhaust away from the
  temperature sensor and allow passive air exchange around both gas cells.

| J2 pin | Signal | Direction relative to Skylark |
| --- | --- | --- |
| 1 | Switched 5 V | Output |
| 2 | Ground | Return |
| 3 | PMS SET, low for sleep | Open-drain control |
| 4 | PMS RX | UART output to sensor |
| 5 | PMS TX | UART input from sensor |
| 6 | PMS RESET, active low | Open-drain control |
| 7, 8 | Reserved | Deliberately unconnected |

## Power and firmware requirements

The [prototype STM32 firmware](../../sw/skylark/README.md) implements sensor
readout, USB streaming and power sequencing. Its image builds and native fault
tests pass; the following physical power/timing checks remain required.

The PMS rail defaults off. Firmware must enumerate and obtain its configured USB
power allocation before enabling it. The 82 kΩ TPS2553 setting gives approximately
284–369 mA current-limit bounds including resistor tolerance, with 323 mA nominal.
Budget another 50 mA for the controller and supporting circuits; the configured
envelope stays below 500 mA. Measure fan startup, fuse drop and actual consumption;
these are design bounds, not bench results. See the [power supply guide](../../docs/power-supplies.md)
for allocations, cable-voltage cases, attach charge, regulator dissipation and
suspend limits. The analog rail has an 8 mA design
budget. The 22 Ω supply filter leaves at least 3.05 V using the stated regulator
and resistor limits; measure this rail over supply and temperature.

The PMS5003 requires at least 4.5 V at its supply. This board does not boost a low
USB voltage. Use a suitable 5 V source and short cable, verify J2 under load, and
invalidate PM measurements on undervoltage or switch fault. The MCU measures the
post-fuse USB rail through a 2:1 divider. Keep the PMS UART output low or high
impedance while that sensor is unpowered to prevent backfeed. Suspend handling
must turn off the PMS and the analog rail, disable the status LED, and put the
MCU and remaining sensors into suitable low-power states. Measure total current
against the applicable USB suspend budget.

The analog rail defaults off through U13 (TPS22918); electrode clamps default
engaged through Q7. PB12 drives ANA_EN, and PB13 drives CLAMP_HOLD (high engages
the clamps). Keep CLAMP_HOLD high while enabling ANA_EN; after the rail and
reference settle, drive CLAMP_HOLD low to release the clamps. Before disabling
ANA_EN, stop conversions and drive CLAMP_HOLD high. Do not sample until the cell
baseline has settled after restarting. Qualify this sequence, reset/brownout
behavior and the clamp gate voltage on hardware. The 10 nF CT capacitor controls
switch slew; firmware timing must account for the measured rail/reference rise.

Q7 is an MMBT3904 with its emitter at VZERO, so an engaged clamp follows the
electrode reference instead of pulling the JFET gates below powered electrodes.
R74 limits base current. D4 isolates the gate pull-up from a falling USB rail;
R71 returns the gate toward VZERO when that supply disappears. Q1–Q4 are
MMBFJ270 devices, specified at 200 pA maximum gate leakage at 25 °C under the
datasheet test conditions. This is not an outdoor-temperature leakage guarantee.
Check gate-to-electrode voltage and discharge behavior during slow ramps,
hard disconnects, MCU reset and brownout with real cells attached.

Sensor power follows USB configuration and suspend state. Closing a CDC data
session leaves the gas bias active; reopening does not repeat conditioning.
The firmware's 60-second gas suppression is a minimum prototype policy. It does
not certify a stable baseline; field software must apply a qualified settling
and calibration policy before interpreting raw readings as gas concentrations.

Use ADS122C04 address 0x40, gain 1, PGA bypassed and the external 2.5 V reference.
Multiplex AIN0–3 as single-ended SO₂ WE, SO₂ AE, H₂S WE, H₂S AE. Start with normal
330 SPS single-shot conversion mode. Eight-millisecond service slots give a
nominal 32 ms period per electrode (31.25 samples/s). The scheduler budgets
100 kHz I²C transactions and enforces a separate five-tick minimum after a new
conversion starts. Service delays extend the schedule rather than restarting
unfinished conversions. Maintain cell bias during normal operation and treat
power-up settling as missing data.

The 15.9 Hz feedback pole and 1.59 Hz output pole provide approximately 33 dB
nominal attenuation at 31.25 Hz. The output filters use 10 kΩ / 10 µF; effective
capacitance under voltage, temperature and aging must be measured. All original
ADC readings are retained. See [sensor bandwidth and timing](../../docs/sensor-response.md)
for the response, ADC-noise tradeoff and remaining qualification requirements.

MCU bindings are PA2/PA3 UART, PB6/PB7 I²C, PA4 PMS enable, PA5 fault, PA6 sleep,
PA7 reset, PB0 ADC DRDY, PB1 ADC reset, PB12 analog enable, PB13 clamp hold,
PA0 supply monitor and PB3 status LED.
Use HSI48/CRS for USB. Set unused GPIOs to an appropriate low-leakage state.

## Validation and limits

Run `python environment/check_project.py`, `./lab.ps1 unit`, and `./lab.ps1 test`
(or `lab.sh`). The full lab builds `skylark` and runs voltage constraints,
independent pin and gain fixtures, bandwidth/headroom and local copper checks,
deliberate fault tests, native DRC/ERC and
compiled/PCB/review-schematic connectivity comparison. Reports are retained in
bounded `.lab/` runs. These tests do not exercise an assembled board.

An optional vendor-model check runs with
`python hw/tools/skylark_spice.py --model /absolute/path/to/OPAx387.LIB`.
Obtain the unmodified model from [TI SBOMBI9](https://www.ti.com/lit/zip/SBOMBI9).
It tests the reference buffer and gas TIAs with native resistor/capacitor values
and a range of assumed capacitive loads. Some exploratory loads produce about
29° phase margin, below the 45° investigation threshold. Actual cell impedance
and guard loading must be established before selecting a compensation change.
These sweeps do not qualify CE/RE loop stability, saturation recovery, startup
or power-off backfeed. The default lab separately checks the 2 µF reference
output capacitance and approximately 42 ms divider settling to 0.1% at the
stated tolerance corner, within the 150 ms rail-wait policy. IC and cell settling
remain additional effects.

Before field deployment, qualify gas bias/stability, baseline/noise, calibration,
cross-sensitivity, airflow and response time; USB enumeration, suspend and signal
integrity; supply and fan startup; socket fit/retention; contamination and weather
exposure; temperature offset from electronics; and the site's pressure.
SGX specifies **800–1200 mbar** for these cells, so high Mount Meager installations
can lie outside the specified pressure range. Do not extrapolate their stated
performance to those sites without characterization.

## Design files

- [Authored circuit](elec/skylark.ato), [atomic parts](../shared/elec/skylark/parts.ato),
  [placement inputs](layout/placement.json).
- [Native PCB](boards/skylark-usb/skylark-usb.kicad_pcb),
  [review schematic](boards/skylark-usb/skylark-usb.kicad_sch),
  [BOM](boards/skylark-usb/bom.csv), [routing snapshot](boards/skylark-usb/skylark-usb.ses).
- [CAD validation](boards/skylark-usb/validation.json),
  [render provenance](boards/skylark-usb/render-provenance.json),
  [model provenance](models/provenance.json). Models are simplified dimension
  envelopes, not supplier STEP geometry. The render shows only the PCB assembly.
- [Printable bell enclosure](mechanical/bell/README.md): separate removable bottom,
  PCB carrier, PMS5003 cradle and cell retainers. Rev G splits the tray, left-side PMS cradle and one splash cover, with
  1,382 mm² of covered bottom gas vents and a 25 mm radius around the upper 25 mm.
  The PMS5003 sits in front of the lower PCB, with two flush
  M4 keyholes and a 25 mm lower skirt.
  Main body is 130 × 94 × 185 mm;
  physical fit and weather qualification remain pending.

`skylark_layout.py` and `skylark_fixed.py` are explicit authoring commands that
replace this product's routing. Do not run them as validation. `skylark_import.py`
checks external router placement before importing; `export_session.py` records
the finished native copper. `skylark_models.py` and `render_skylark.py` regenerate
portable package models and actual KiCad renders.

## Manufacturer references

- SGX [SO₂ DS-0685](https://sgxsensortech.com/uploads/f_note/DS-0685-SGX-7SO2-AQ-20.pdf),
  [H₂S DS-0681](https://sgxsensortech.com/uploads/f_note/DS-0681-SGX-7H2S-AQ-25.pdf)
  and [electrochemical electronics application note](https://www.sgxsensortech.com/content/uploads/2014/08/A1A-EC_SENSORS_AN2-Design-of-Electronics-for-EC-Sensors-V4.pdf).
- TI [OPA387/OPA2387](https://www.ti.com/lit/ds/symlink/opa2387.pdf),
  [ADS122C04](https://www.ti.com/lit/ds/symlink/ads122c04.pdf),
  [REF3025](https://www.ti.com/lit/ds/symlink/ref3025.pdf),
  [TPS2553](https://www.ti.com/lit/ds/symlink/tps2553.pdf),
  [TPS22918](https://www.ti.com/lit/ds/symlink/tps22918.pdf).
- ADI [CN0396 electrochemical sensor reference circuit](https://www.analog.com/media/en/reference-design-documentation/reference-designs/cn0396.pdf):
  low-frequency amplifier noise and analog filtering guidance.
- [STM32F072 datasheet](https://www.st.com/resource/en/datasheet/stm32f072cb.pdf),
  [SHT4x datasheet](https://sensirion.com/resource/datasheet/sht4x),
  [BMP388 datasheet](https://www.bosch-sensortec.com/media/boschsensortec/downloads/datasheets/bst-bmp388-ds001.pdf),
  [MMBFJ270](https://www.onsemi.com/download/data-sheet/pdf/mmbfj270-d.pdf),
  [MMBT3904](https://www.onsemi.com/download/data-sheet/pdf/mmbt3904lt1-d.pdf),
  [BAT54](https://www.onsemi.com/download/data-sheet/pdf/bat54lt1-d.pdf).
- [Mill-Max receptacle catalogue](https://www.mill-max.com/sites/default/files/external/catalog/2020-03/153-201_0.pdf),
  [Amphenol 20021111 header](https://cdn.amphenol-cs.com/media/wysiwyg/files/drawing/20021111.pdf).

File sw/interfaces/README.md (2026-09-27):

# Sensor interfaces

[Sensor contract v1](../../docs/sensor-contract.md) defines units, time, bounds,
loss and USB framing. Protobuf lives under `proto/`; `buf.yaml` enables STANDARD
lint and FILE compatibility checks. `baseline.binpb` is the frozen initial
descriptor, intentionally tracked as a compatibility fixture. Do not regenerate
it just to make a breaking check pass. Change it only for an explicitly reviewed
new contract version, with migration fixtures.

From the repository root, build the updated portable image once with
`./lab.ps1 build`, then run `./lab.ps1 test -Profile software`.
The full and quick profiles also run these checks. On Linux use
`sh ./lab.sh test --profile software`.

Buf 1.73.0 is SHA-256 pinned in `environment/install_buf.py`; the reference
Python codec uses Protobuf 5.29.6 from the existing locked environment. Tests
need no network or hardware. The descriptor and verification output are built
inside the disposable workspace at `sw/build/`, never added to source control.
The lab retains a small report with its usual five-run retention/cleanup.

`python/` contains the reference validator and incremental framing decoder.
`sensor.options` records candidate Nanopb bounds; it is not generated firmware.
The [Pi application](../pi/README.md) uses these contracts for modeled/Linux
adapters, recording/replay and USB input. Real sensor and firmware qualification
remain separate from software checks.

Skylark adds board ID 3 and sensor IDs 10–16 without changing prior field numbers
or the frozen baseline. Its firmware emits v1 through a bounded C encoder;
native tests decode that output with the Python reference runtime. Raw gas
channels, complete PM/SHT frames, and BMP raw/factory trim remain in recordings.

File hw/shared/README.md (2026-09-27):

# Shared hardware resources

- `elec/`: shared atomic part definitions, their footprints and symbols.
- `libraries/`: KiCad footprint libraries used by the native projects.
- `models/`: component and assembly models, including vendor attribution.
- `reference/`: component reference material.
- `vendor/`: preserved upstream hardware and licenses.
- `simulation/`: common and legacy cross-board supporting-circuit simulations.

Product circuits, placement and routed CAD live in their respective product
directories. Keep reusable resources here rather than copying them into each
product. The `elec/` and `libraries/` footprint copies serve different existing
atopile/KiCad consumers; maintain their agreement.

Shared authoring and validation tools remain in [../tools/](../tools/), and
their existing regression suite remains in [../tests/](../tests/). Product paths
are resolved through [project_paths.py](../tools/project_paths.py).

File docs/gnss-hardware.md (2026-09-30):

# Groundlark GNSS and antenna

DAQHAT-01 fits **u-blox MAX-M10S-00B (U21)** on the underside. It uses Pi I²C1
at address **0x42**, powered from PI_3V3. TIMEPULSE connects directly to
**BCM24, header pin 18**. The geophone retains BCM4 DRDY; BCM6/13 retain the
power-supervisor handshake. FPGA connections and its separate supply remain
unchanged. GNSS needs no configured FPGA.

The Pi and GNSS face ISO1640 side 2 (pins 6–8). Its 0.4 V maximum low output
fits the MAX-M10S 0.63 V low-input limit. The sensor bus faces side 1, whose
0.71 V maximum low output fits the sensors’ 3.3 V input thresholds. Keep the
C48 sensor-side and C49 Pi-side supply bypass assignments with this orientation.

## Antenna connection

J140 is a HenryTech **HL-SMA-KWE-02**, conventional female SMA, 50 ohms.
Use a matching male SMA plug, not RP-SMA. It faces native PCB -X, which becomes
physical enclosure +X after stack rotation. The R3 side slot admits a coupling
nut up to 10 mm diameter; the connector is recessed, so verify access with the
actual cable before printing a batch. Support the cable to avoid bending the PCB.

Use a GNSS antenna rated for **3.3 V bias and at most 20 mA**. U140 TPS70933
derives its supply from switched PI_5V, with local 4.7 µF input/output bypass.
U141 TPS2553 follows the LDO. ILIM and EN connect to its input, selecting a
50–100 mA sustained current limit (75 mA typical), below L140’s 280 mA rating.
C152 (100 nF) bypasses the limiter input. C151 (10 nF) bypasses the cold end of
L140 beside the SMA with a local ground-plane stitch. L140 (27 nH) feeds DC onto
the coax; C148 (47 pF C0G) blocks antenna DC at RF_IN.
D140 PESD5V0F1BL provides 0.4 pF nominal ESD protection. There is no antenna
open/short telemetry; the limiter’s unused open-drain FAULT output is NC.
Current-limit response, repeated shorts and thermal recovery require physical
fault testing. The 20 mA antenna allocation is separate from the fault limit.
Do not connect an externally powered coax source that supplies DC to J140.

U21 has 4.7 µF and 100 nF local bypass. EXTINT is grounded. Unused UART,
RESET_N, SAFEBOOT_N, VIO_SEL, VCC_RF, LNA_EN and V_BCKP remain unconnected per
the selected interface; no backup cell is fitted. Removing Pi power also removes
receiver and antenna power. Each start must reacquire satellites.

Allow 75 mA from PI_5V and 150 mA from PI_3V3 for the HAT, including the
receiver's 100 mA acquisition allocation and antenna. These allocations sit
inside the supervisor's **3 A combined Pi/HAT** limit; USB accessories and Pi
workload consume the same budget. Measure rail droop, startup and temperature.

## Placement and qualification

Place the antenna outside the enclosure with the widest practical sky view.
Mountains and foliage can block satellites; do not accept an indicated fix as
proof of timing quality. Record lock loss and PPS gaps during representative
terrain tests. Keep antenna cable away from the geophone lead and switching
power inputs. The vented R3 case has no outdoor ingress rating.

The PCB keeps the RF input on B.Cu beside the connector with a ground reference
on In4.Cu and through-hole SMA grounds. The short RF layout uses the existing
stock six-layer stack. It has **no controlled-impedance fabrication claim**;
measure insertion loss/return loss, satellite C/N0, ESD behavior and receiver
performance with the FPGA and power converters active before release.

Use [`live --fifo --utc`](utc-timing.md) to capture receiver configuration,
TIM-TP, NAV-TIMEUTC and kernel PPS events. The application owns BCM24; do not
also enable `pps-gpio`. UTC correlation requires a recording-bound policy with
measured bounds. GNSS does not remove ADC/filter delay or Linux acquisition
uncertainty. The present geophone polling path is not a verified 1 ms sample
timestamp source. Calibrate delays against a common physical stimulus/reference
across stations before claiming millisecond alignment.

## Parts and source drawings

| Part | Catalog identity | Manufacturer evidence |
| --- | --- | --- |
| MAX-M10S-00B | JLCPCB C4153167 | [u-blox integration manual](https://content.u-blox.com/sites/default/files/MAX-M10S_IntegrationManual_UBX-20053088.pdf) |
| HL-SMA-KWE-02 | JLCPCB/LCSC C20617216 | [HenryTech drawing](https://datasheet.lcsc.com/datasheet/pdf/b2f602368ae573f1e0d7be688540576e.pdf?productCode=C20617216) |
| TPS2553DBVR | JLCPCB C55266, SOT-23-6 | [TI datasheet](https://www.ti.com/lit/ds/symlink/tps2553.pdf) |
| TPS70933DBVR | TI, 3.3 V antenna regulator | [TI datasheet](https://www.ti.com/lit/ds/symlink/tps709.pdf) |
| PESD5V0F1BL,315 | Nexperia, SOD882 | [Manufacturer specification](https://www.nexperia.com/product/PESD5V0F1BL) |

Confirm stock and assembly eligibility at order time. The SMA footprint follows
the drawing's 5.10 mm ground-pin pitch, four 1.50 mm ground drills and 1.20 mm
center drill. The authored STEP uses the same drawing and is an envelope, not
a supplier-certified mating solid. Supplier rotation/package approval remains
part of assembly release.

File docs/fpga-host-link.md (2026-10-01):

# DAQHAT-01: internal Pi / Trenz transport

The 140 × 56 mm HAT now connects the Pi directly to the TE0712-03-81I36-A.
Six wires reserve SPI/QSPI, UART is retained, and a switch shares four wires
with dedicated FPGA JTAG. J84–J89, their expansion fanout, all four ribbons,
the guide and the offset spacer are removed from the active assembly.
The Pi stays below the HAT; the FPGA stays above it for cooling access.

## Wiring and power

| Function | Pi physical pin / BCM | Carrier / module contact | FPGA ball |
| --- | --- | --- | --- |
| SCLK / JTAG TCK | 40 / 21 | J81.21 / JM2.22 | W19 |
| CS_N | 12 / 18 | J81.23 / JM2.24 | W20 |
| DQ0 / MOSI / JTAG TDI | 38 / 20 | J81.22 / JM2.21 | V18 |
| DQ1 / MISO / JTAG TDO | 35 / 19 | J81.24 / JM2.23 | V19 |
| DQ2 / JTAG TMS | 36 / 16 | J81.26 / JM2.25 | Y18 |
| DQ3 | 32 / 12 | J81.28 / JM2.27 | Y19 |
| Pi TX / FPGA UART RX | 8 / 14 | J81.12 / JM2.11 | AA21 |
| Pi RX / FPGA UART TX | 10 / 15 | J81.14 / JM2.13 | AA20 |
| Application reset control | 11 / 17 | J81.13 / JM2.14, through existing transistor | AB22 |

In programming mode the switch selects dedicated JTAG contacts J81.94/96/98/100,
not the application balls in the table. R80 keeps the module CPLD's JTAGEN low.
The complete [contact map](trenz-pin-map.json) includes 149 unused ordinary I/Os;
the audit checks all 260 module contacts against independent vendor fixtures.
Sensors retain SPI0, I2C1 and their existing interrupts. The added DLVR U23
uses I2C1 address 0x28, alongside the 0x20 link expander and 0x40 geophone ADC.
It consumes no additional Pi or FPGA pins; BCM6/13 serve power management; BCM24 carries GNSS PPS. Ethernet is not exposed.

U100/U101 are TMUX1574 bidirectional switches. U102 is a TCA9534 at I2C1 address
0x20: P0 selects JTAG; P1 requests enable. U103/U106 permit a connection only
with the request, BCM25 arm and both rail-good signals asserted. BCM25 also
retains its existing UART-enable role. The link tool owns BCM25 while running;
do not run a separate UART-enable controller concurrently.

U104/U105 monitor Pi/FPGA 3.3 V with TLV809EA30DBZR supervisors (3.0 V threshold,
nominal 200 ms release). Each new IC has local 100 nF decoupling. R100–R105 are
22 Ω series footprints; pulls define reset/idle states. The switch's unselected
CS/DQ3 parking contacts are open, so they cannot short Pi outputs to ground.
TMUX1574 provides powered-off signal isolation at VDD=0 and fail-safe controls.
Settled-state simulation does not characterize subthreshold power ramps.

J83 uses a separate Nexys-compatible 12 V adapter; see the [converter and operating envelope](trenz-hat.md#power-and-interfaces).
The [assembly guide](stack-assembly.md) specifies the existing GPIO riser and
four straight supports. Use the recorded six-layer stock stack and fill/cap all through-vias,
including the ADC supply vias and the through-via at U101.4.

## Initial transport and bitstream

Pi 4 uses **SPI6, mode 0, CE0 only, initially ≤1 MHz**. DQ2/DQ3 are reserved;
its Linux SPI controller does not perform native quad transfers. The reference
bitstream advertises no quad capability. JTAG runs at a requested 100 kHz;
measure the actual clock before changing the native GPIO adapter calibration.

The [reference RTL](../sw/fpga/rtl/daqhat_01_link.sv) is an echo/mailbox bring-up design.
It uses the module's default 50 MHz CLK50M2 at R4; the exact revision-03 schematic
shows its 1.5 V level translation and bank supply, so its XDC uses LVCMOS15.
Application bank 14 uses LVCMOS33. The bitstream does not configure DDR, Ethernet
or the Si5338. Verify the clock generator still has its factory settings.

At this conservative rate, SPI is oversampled in one 50 MHz domain through
three-stage synchronizers. A one-frame mailbox replaces the proposed asynchronous
FIFO: there is no second fabric clock domain to cross. CS setup/hold and the
interval between transactions must each be at least 1 µs; SCLK high/low at least
500 ns. The overlay requests 1 µs CS setup/hold/inactive delays through the Linux SPI
core; use a kernel supporting those properties (reviewed against Pi Linux 6.12).
The Pi tool checks the overlay and inserts a 1 ms transaction gap. MISO is undriven immediately
when CS is high. UART has electrical loopback for separate diagnostic testing.
Unused quad ports are optimized out; the bitstream leaves unused pins undriven.

Vivado 2025.2 built the XC7A200T-FBG484-1 bitstream. Recorded timing is +10.143 ns
setup / +0.109 ns hold slack at 50 MHz, zero internal unconstrained endpoints;
see [reports and source hashes](../sw/fpga/verification/result.json). Asynchronous
input exceptions and bounded output propagation are explicit in the XDC.
These reports do not qualify the Pi controller, switch or board timing.

## Wire contract

Every command is one CS-delimited transaction, MSB-first within each byte.
The first received byte is a dummy. Multi-byte integer fields are little-endian.

| Command | Bytes after command | Behavior |
| --- | --- | --- |
| 0, status | Clock 8 zero bytes | `SSFP`, version 1, capabilities 0, flags, error |
| 1, submit | Exact encoded frame | Commit only at CS release after length and CRC validation |
| 2, read | Clock 206 zero bytes | Result frame padded with zeroes; repeated reads do not consume it |
| 3, acknowledge | uint16 sequence | Free only the result with this sequence |

Flags: 0 busy, 1 empty, 2 result available. Frame: `SSFP`, version byte 1,
operation byte 1 (echo), uint16 sequence, uint16 payload length, 0–192 payload
bytes, CRC-32/IEEE over header and payload, stored little-endian. Maximum 206 bytes.
Status errors are sticky until application reset/reconfiguration: 1 overflow,
2 invalid frame, 3 CRC, 4 incomplete transaction, 5 busy write, 6 wrong ACK,
7 unknown command. Busy writes preserve the existing result. Invalid results
are never acknowledged by the Python client. A timed-out write has unknown
outcome; the client does not automatically repeat it.
The processing timeout is checked before and after each status transaction;
late ready responses are not consumed. ACK completion requires a subsequent empty
status. An interrupted reset discards the current transaction through CS release;
MISO is undriven during reset, and the next complete transaction starts cleanly.

## Bring-up

Install the sensor overlay first. Compile the optional
[`groundlark-fpga-overlay.dts`](../sw/pi/deploy/groundlark-fpga-overlay.dts)
with `dtc -@ -I dts -O dtb`, install it in the Pi's overlays directory and add
`dtoverlay=groundlark-fpga` to the active boot configuration. Enable I2C1.
Do not combine with other SPI1/SPI6 or GPIO18–21/12/16 consumers. CE1 remains
disabled because BCM27 belongs to IMU1. Ensure the `spidev` module is loaded.

The following commands run **on the Pi**, from the repository, after verifying
which gpiochip represents BCM2711. OpenOCD 0.12.0 with bcm2835gpio is required.

```sh
sudo python3 sw/tools/fpga.py scan --gpiochip /dev/gpiochip0
sudo python3 sw/tools/fpga.py program --gpiochip /dev/gpiochip0 --bitstream /path/to/daqhat-01-link.bit
sudo python3 sw/tools/fpga.py status --gpiochip /dev/gpiochip0
sudo python3 sw/tools/fpga.py loopback --gpiochip /dev/gpiochip0
```

The tool locks the link, disarms it, initializes the expander's output latch
before directions, and verifies register readback. For JTAG it unbinds SPI6's
controller, claims safe GPIO directions, then enables the switch. It isolates
before restoring SPI6. GPIO25 provides disarm even if I2C fails; I2C disable
is attempted even if the GPIO operation fails. A control-bus failure keeps
ownership faulted; restore power/control and reinitialize before reuse. Driver
restoration failure also latches this fault. SIGTERM and Ctrl-C unwind the
isolation path. Termination that bypasses cleanup (including SIGKILL) has no hardware watchdog: GPIO output
state may remain latched. Restart through this tool (which first drives BCM25
low), or power-cycle/reboot before manual driver changes. Reboot restores a
controller left unbound. Sensor acquisition remains independent.
Programming loads volatile FPGA configuration only; it does not write flash.

Build the bitstream from an ignored output directory using Vivado:

```text
vivado -mode batch -source /absolute/path/to/groundlark/sw/fpga/build.tcl
```

## Verification and remaining measurements

The portable lab includes RTL packet/fault simulation, production Python-to-RTL
co-simulation, host framing/ownership tests, 38 behavioral-switch/RC checks,
native CAD checks and sensor regressions. Full and quick profiles now run
`hw/tools/replay_trenz.py`, rebuilding the complete native routing in a
temporary directory and comparing every copper object. A separate parts fixture
checks all 32 link components against authored metadata, BOM and PCB fields.
Current rendered and
interactive models use the revised board; the Pi model remains conceptual.

Still measure first-article rail ramps/current, actual stack seating, SPI/JTAG
edges and switching, and sensor noise with the FPGA idle and active. Linux driver
handoff and JTAG programming have not been exercised on a physical Pi/Trenz stack.
Quad throughput and accelerated processing remain future work.
See [assembly requirements](jlcpcb-assembly.md) and the
[bench procedure](bench-procedure.md) for production preparation and physical qualification.

Sources: [exact module schematic](vendor/trenz/SCH-TE0712-03-81I36-A.PDF),
[TMUX1574](https://www.ti.com/lit/ds/symlink/tmux1574.pdf),
[TCA9534](https://www.ti.com/lit/ds/symlink/tca9534.pdf),
[SN74LVC1G10](https://www.ti.com/lit/ds/symlink/sn74lvc1g10.pdf),
[SN74LVC1G08](https://www.ti.com/lit/ds/symlink/sn74lvc1g08.pdf),
[TLV809E family](https://www.ti.com/lit/ds/symlink/tlv803e.pdf).

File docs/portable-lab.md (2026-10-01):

# Portable test environment

**DAQHAT-01 GNSS revision:** MAX-M10S-00B uses Pi I2C1 and BCM24 PPS alongside the Racotech geophone. Portable tests exercise modeled timing; physical millisecond alignment remains unqualified.

The project now has one disposable Docker test environment. Keep authored files
in their existing locations and use the root `lab.ps1` or `lab.sh` launcher for
validation. Existing local virtual environments and historical reports are not
required by this runner and are not removed by cleanup.

## Start here

Prerequisites: Docker with Linux containers, Python 3.12 or newer, and enough
Docker memory for an 8 GiB container. Both are already available on the current
Windows machine. The toolchain is Linux/amd64; other host architectures require
Docker's amd64 emulation and have not been verified.

From the project folder in PowerShell:

```powershell
.\lab.ps1 build                 # Once; needs Internet
.\lab.ps1 doctor                # Show exact installed tool versions
.\lab.ps1 test                  # Full circuit + PCB + SPICE validation
.\lab.ps1 test -Profile quick   # Saved compiled circuit/PCB + SPICE checks
.\lab.ps1 test -Profile spice   # Only bounded SPICE cases
.\lab.ps1 test -Profile software # Sensor application, contracts and recovery
.\lab.ps1 unit                  # Cleanup/staging safeguards
```

On Linux/macOS, use `sh ./lab.sh build`, `sh ./lab.sh test`, and
`sh ./lab.sh test --profile quick`. Alternatively, run
`python environment/host.py test` on Windows or `python3 environment/host.py test`
elsewhere. Paths are relative to the launcher, not the current working directory.
No global Python packages or project virtual environments are installed.

Windows Docker Desktop could not bind-mount this machine's `P:` drive. The
launcher therefore sends an allowlisted source snapshot through Docker's API,
runs against that copy, and copies reports back. This also works without Docker
drive-sharing configuration. No host directory is mounted into the container.

## What each profile proves

| Profile | Checks |
| --- | --- |
| `full` (default) | Fresh atopile builds for Burrowlark DAQUSB-01 USB field head, DAQHAT-01 and Skylark; numeric constraint solves; unsafe 5 V IMU rejection; independent hardware regressions; native KiCad ERC/DRC/connectivity; DAQHAT-01 power/clearance and pre-fab review; clean routing replay; SPICE; the software profile (25 stages). |
| `quick` | Same GPIO/component fault, circuit/PCB consistency, routing replay, SPICE and software checks using saved compiled layouts. Does **not** prove `.ato` changes were rebuilt. |
| `spice` | 18 shared/USB, 14 Trenz, 15 geophone response, 8 geophone transient and 38 host-link switch/RC cases, including expected fault detection. |
| `software` | RTL and Python-to-RTL co-simulation; recorded Vivado evidence/hash gate; Buf format/lint/build and compatibility; acquisition/replay, modeled driver and Linux TTY/worker fault tests; retained acquisition demo; Skylark native C fault tests and ARM firmware build. No physical hardware execution. |

The runner calls the existing project entrypoints. Routing reconstruction stays
in a temporary tree; it does not rewrite source CAD, render images, or release fabrication files. A full test
compares freshly compiled connectivity with the saved routed boards and should
fail if they disagree.

The runner records every check, including checks after a failure or timeout.
Any failed check still fails the overall run; `run.json` lists `failed_steps`
and each check has its own log. In particular, an assembly-registry mismatch
does not suppress the later circuit, SPICE or software results. Checks with
missing build prerequisites can fail as well; inspect the earlier build logs.

These are bounded electrical models, RTL simulations and CAD checks. They do not
emulate sensor silicon, USB enumeration, a booted Raspberry Pi or FPGA execution.
They do not establish regulator stability, extracted signal/power integrity,
thermal performance, physical mating, or fabrication readiness.

## Where files go

```text
groundlark/
  hw/                circuits, routed CAD, models and hardware checks
  sw/                Pi software, USB firmware and FPGA integration scopes
  docs/              shared design and interface documentation
  environment/       small runner, Dockerfile, dependency lock and safety tests
  lab.ps1 / lab.sh   entrypoints
  .local/            ignored local tools and preserved legacy caches
  .lab/
    .groundlark-lab   ownership marker
    .lock            prevents simultaneous run/cleanup
    runs/<run-id>/   status, input hashes, tool versions, logs, result files
```

The source snapshot, build tree, package caches and tool temporary files live
inside memory-backed container filesystems and disappear when the container
exits. The test process runs without root privileges. Input files are owned by
root and read-only to that process; the container root filesystem is read-only.
There are no persistent Docker volumes, hardware passthroughs, host-network
access, or mounted Docker sockets.

Containment limits:

- Keep the **five newest runs**, including failures. Before a new run, older
  marked runs are removed automatically. Save evidence you need to keep outside
  `.lab` before the next run; do not treat `.lab` as an archive.
- Scratch workspace: 2 GiB; tool temporary files: 512 MiB; source snapshot:
  512 MiB; reports inside a run: 256 MiB. Individual logs/files: 32 MiB.
- Refuse to start if retained host data exceeds 1 GiB after retention cleanup.
  This is a start check, not a host filesystem quota.
- Container: 8 GiB RAM, four CPUs, 256 processes. Each test step times out after
  ten minutes. A container abandoned by a terminated launcher expires after one
  hour. Normal success/failure stops and removes it immediately.
- Test runs use no network. Dependencies are downloaded only during image build.

Each report identifies the exact image ID and tool versions, hashes the inputs,
records step outcomes, and includes generated SPICE decks and logs. The launcher
checks that the host inputs did not change during the run. Reports are copied
back after execution; forcibly terminating Docker can lose that run's in-memory
details. Its host status marker remains for diagnosis and later cleanup.

## Cleanup

```powershell
.\lab.ps1 clean                 # Preview old runs beyond the newest five
.\lab.ps1 clean -Apply          # Remove those old runs
.\lab.ps1 clean -All            # Preview removing every run
.\lab.ps1 clean -All -Apply     # Remove all disposable test evidence
```

Equivalent shell flags are `clean --apply` and `clean --all --apply`. Cleanup
works without Docker. It requires the lab ownership marker, validates every run
marker and final absolute path, refuses symlinks/junctions and unknown folders,
and acquires the same lock used by tests. It only removes recognized run folders.
It leaves authored files, CAD, existing virtual environments, and the old `C:`
project copy alone. An unexpected folder causes cleanup to stop for inspection.

The reusable Docker image and Docker build cache live in Docker Desktop's disk,
outside `.lab`. The installed image reports about 2.92 GB, including 2.25 GB
shared with its KiCad base. Normal test runs do not rebuild or grow this image.
Use `docker system df` to inspect storage. To remove this
project's image, use `docker image rm groundlark/lab:1` after tests have stopped.
Do not use global `docker system prune` or `docker volume prune` as project
cleanup: other projects share this Docker installation.

## Moving or updating it

Clone the Git repository, or copy the authored project and environment directory
(excluding `.lab/` and `.local/`) to another machine,
then run `build`. No absolute `C:` or `P:` paths are encoded in the runner. The
image pins the KiCad base and uv installer by digest; atopile 0.15.9 and its
transitive Python dependencies are pinned with package hashes. Python is 3.14.7.
Device-tree compiler 1.6.1-4+b1 supplies real overlay compile/merge tests.
The KiCad base supplies KiCad 9.0.9 and ngspice 39; previous WSL validation used
ngspice 42. The reports explicitly record this difference.

For an offline transfer, optionally save a **single image archive**:

```powershell
docker save -o groundlark-lab-image.tar groundlark/lab:1
# On the receiving machine:
docker load -i groundlark-lab-image.tar
```

Keep that archive on transfer storage, not in the source repository or `.lab`.
Source plus an exported image gives a stronger toolchain snapshot than rebuilding
from online registries. Container runtime/kernel versions still vary by host.
The checked-in `requirements.lock` is consumed directly; the old project venvs
are never copied. `installed-constraints.txt` records the versions used when
creating that lock. Update pins deliberately and rerun the complete suite.

An [inactive GitHub Actions template](../environment/ci/README.md) can run the
structure checks, cleanup tests, and full hardware profile on pushes and pull
requests, with report retention of seven days. It has not been installed because
the current GitHub login lacks workflow-management scope. The local suite is
fully usable. The software/full/quick profiles validate the sensor application,
contracts, framing, recording/replay and bounded recovery. Skylark’s production
C sensor/encoder and flash-journal code run against native fault fixtures, and
the STM32 ARM image is linked. Physical device behavior and USB enumeration
remain outside these checks.
Buf 1.73.0 is downloaded only during image build and SHA-256 checked; Protobuf
5.29.6 reuses the existing Python lock. Runtime tests remain offline.

The image also contains native GCC, ARM GCC 12.2.1, newlib headers and a pinned,
SHA-256 verified libopencm3 source/build. Rebuild with `lab.ps1 build` after this
toolchain change. Tool versions and the libopencm3 revision are recorded with
each run. No network access is needed during software tests.

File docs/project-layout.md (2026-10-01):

# Project organization

| Location | Purpose |
| --- | --- |
| [hw/groundlark-fpga-hat/](../hw/groundlark-fpga-hat/README.md) | DAQHAT-01 Trenz FPGA HAT; active prototype. |
| [hw/burrowlark-usb/](../hw/burrowlark-usb/README.md) | DAQUSB-01 magnetometer USB sensor head. |
| [hw/skylark-usb/](../hw/skylark-usb/README.md) | Rev A USB air-quality circuit, routed PCB and bell enclosure; physical qualification pending. |
| `hw/ato.yaml` | Shared build registry: `trenz_hat`, `hat`, `field_head` and `skylark`. |
| `hw/shared/elec/` | Common atomic parts and component assets. |
| `hw/assembly/<product>/` | Product-specific procurement and assembly overrides. |
| `hw/releases/<product>/` | Ignored local manufacturer review packages with explicit release status and hashes; not published without an explicit request. |
| `hw/shared/libraries/`, `hw/shared/models/` | Shared KiCad symbols/footprints and local 3D models. |
| `hw/tools/`, `hw/tests/`, `hw/shared/simulation/` | CAD tooling, electrical fault fixture, bounded SPICE models and recorded results. |
| `hw/shared/reference/`, `hw/shared/vendor/` | Component references and upstream board material. |
| `sw/interfaces/` | Versioned Protobuf, compatibility baseline, reference validation/framing. |
| `sw/tools/` | Offline schema and software check entrypoint. |
| `sw/pi/` | Pi drivers/configuration, acquisition, calibration and recording/replay. |
| [sw/skylark/](../sw/skylark/README.md) | Skylark STM32 firmware and native hardware-abstraction fault fixtures. |
| `sw/field-head/` | Planned Burrowlark DAQUSB-01 USB microcontroller firmware. |
| `sw/fpga/` | Trenz SPI echo bitstream, host-link checks and board constraints. |
| `sw/tests/` | Contract, acquisition, recording, recovery and FPGA-link tests. |
| `sw/ui/` | Python/NiceGUI workbench, locked optional dependencies and display assets. |
| `docs/` | Setup, hardware specifications, assembly, interface contracts and testing instructions. |
| `environment/` | Pinned portable toolchain, launcher implementation and safeguard tests. |
| `.lab/` | Ignored disposable reports, bounded by retention. |
| `.local/` | Ignored local dependencies and preserved legacy caches. |

Run the root `lab.ps1` / `lab.sh` commands from any working directory. Low-level
commands documented elsewhere assume the repository root as the working directory.
The atopile project itself is now `hw/`, so direct builds must target that directory.

Each implemented product owns its `elec/` circuit sources, `layout/placement.json`,
`layout/<target>/` compiled connectivity and `boards/<board>/` native CAD and
validation artifacts. Product-specific mechanical and simulation files stay with
the product. Shared tools resolve these locations through `hw/tools/project_paths.py`.
Native board names are retained to preserve model and build identities.

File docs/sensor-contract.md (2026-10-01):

# Sensor contract v1

`Calibrated.geophone_input_v` (optional field 7) carries measured J90 differential volts from a static electronics calibration. It is not velocity. Raw ADC counts remain unchanged. Version 2 calibration artifacts bind to device identity and effective sensor configuration; see [calibration](calibration.md).

Status: implemented schema, Python reference checks and USB framing; Pi drivers and Skylark STM32 firmware implemented; Burrowlark firmware and physical qualification remain pending. This document owns semantic rules. The
[Protobuf schema](../sw/interfaces/proto/groundlark/sensor/v1/sensor.proto) owns
field numbers/types. Both apply. A configured FPGA is unnecessary.

## Identity and versioning

Every Envelope has version 1, a nonempty device_id of at most 32 ASCII characters
from letters, digits, underscore, dot, colon and hyphen, and a nonzero fixed64
boot_id. Device IDs are provisioned physical/logical producer identities, never
USB port paths. Pi software generates a fresh random boot_id at each acquisition
session; the MCU needs a persistent counter or host-provided session nonce before
streaming. Reusing boot_id after a reset is prohibited. Identity is advertised
before configuration or data and after reconnect.

One envelope contains identity, effective configuration, a sample batch, or
status. Unknown envelope versions/body kinds and enum values are rejected.
Unknown additive Protobuf fields are preserved by the reference parser and may
be ignored by consumers. Never reuse field numbers; reserve removed names and
numbers. Buf FILE rules compare against the checked-in initial descriptor
baseline. Changes to these semantic rules need review even if Buf accepts them.
Breaking meaning/units requires a new package and envelope version.

| Sensor ID | Board and model | Raw representation |
| --- | --- | --- |
| 1–3 | DAQHAT-01 LSM6DSO U11–U13 | Signed 16-bit XYZ acceleration/gyro counts; optional signed temperature |
| 5 | Legacy SCL3300 U20 (removed from current DAQHAT-01) | Signed 16-bit XYZ acceleration and/or angle counts, optional temperature, required 16-bit device status |
| 6 | Legacy DAQHAT-01 MAX-M10S U21 (absent on DAQHAT-01) | Complete 92-byte UBX NAV-PVT payload, excluding UBX header/checksum |
| 7 | USB head RM3100 | Signed 24-bit XYZ counts, sign-extended into sint32 |
| 8 | DAQHAT-01 DLVR U23; legacy USB head supported | Four original response bytes, preserving pressure, temperature and status bits |
| 9 | DAQHAT-01 ADS122C04 / Racotech vertical | Signed 24-bit ADC count in sint32; required uint8 conversion counter |
| 17 | Burrowlark SHT45 U6 | Six original temperature/humidity bytes, including both CRC bytes |

Skylark uses board ID 3 and MCU clock domain 2:

| Sensor ID | Model/channel | Raw representation |
| --- | --- | --- |
| 10 / 11 | SGX-7SO2-AQ-20 working / auxiliary | Independent signed 24-bit ADC count and required uint8 conversion counter |
| 12 / 13 | SGX-7H2S-AQ-25 working / auxiliary | Independent signed 24-bit ADC count and required uint8 conversion counter |
| 14 | PMS5003 | Complete 32-byte frame, including header, length and checksum |
| 15 | SHT40 | Six original temperature/humidity bytes, including both CRC bytes |
| 16 | Bosch BMP3 (current BMP388; legacy BMP390) | Six pressure/temperature bytes, plus all 21 factory trim bytes |

Skylark's fixed profile uses external 2.5 V reference, gain 1, PGA bypass and
normal 20 SPS single-shot ADC conversions: AIN0/1/2/3 map to IDs 10/11/12/13.
Each channel's nominal publication period is 240,000,000 ns. IDs 14–16 use
1,000,000,000 ns. Other settings are rejected by this profile. Sensor 15 uses
high precision with no heater; sensor 16 uses pressure ×8 / temperature ×2
oversampling at 3.125 Hz with IIR off. A different profile needs explicit schema
and driver support before use. See [firmware operation](../sw/skylark/README.md).

PMS frames require header `42 4d 00 1c`, sum of bytes 0–29 equal to the final
big-endian uint16, and error byte 29 zero for usable samples. Atmospheric
PM1/PM2.5/PM10 are the big-endian uint16 fields at offsets 10/12/14 (µg/m³).
SHT words each use CRC-8 polynomial 0x31, initial 0xFF. BMP raw values are
unsigned 24-bit little-endian pressure then temperature, with original trim.
Host display uses Bosch factory compensation and SHT's transfer equations;
recorded bytes are unchanged. No gas calibration or concentration is implicit.

Firmware identity lists the board's fitted inventory. Failed device probes
remain in configuration as disabled entries with period zero. Gas-cell presence
cannot be detected merely by successfully probing the shared ADC. Warmup,
invalid/stale frames and unavailable conversions produce missing samples with
no raw payload. Loss is unknown where acquisition history cannot establish it.
The firmware's MCU timestamps are scheduler timestamps with unknown acquisition
uncertainty; no host/MCU/UTC correlation is claimed.

ID 9 uses the Pi MONOTONIC_RAW clock, gain 64, reference 2.048 V and nominal
period 3,030,303 ns (330 SPS). ADC input volts = count × reference / (gain × 2²³).
Velocity requires frequency-response correction and calibration; none is implicit.
The current DAQHAT-01 inventory is 1–3, 8 and 9. IDs 4, 5 and 6 retain their
legacy IMU, inclinometer and GNSS semantics. None is advertised by current acquisition.

The model is fixed by v1 sensor ID. Another model requires explicit schema
evolution, not relabeling. Identity advertises only physically fitted sensors;
the DNP pressure sensor is absent by default. Identity.firmware_version is the
producer software build ID, including for the Pi. Raw axes are each package's
documented axes, without inferred board alignment. The three IMUs remain separate. Sensor ID 4 retains its IMU wire semantics for legacy recordings; the current HAT does not advertise it.
Legacy tilt angles retain the manufacturer's per-axis convention; they are not Euler
angles. The acquisition adapter must check SPI/UBX integrity before publishing.

## Configuration and interpretation

Configuration advertises an **effective** revision greater than zero. Revision
increases within a boot; it changes whenever sampling mode, range or configuration
changes. A batch names exactly that revision. Receivers must reject/quarantine
data until the matching identity and configuration have been received. No
unacknowledged control command is defined by this milestone.

Up to eight unique sensor entries are allowed. Enabled entries have a positive
nominal period_ns, at most 60 seconds. Disabled entries have period zero.
The period is a requested/effective nominal interval, not proof that a device
supports the rate; the real adapter must reject unsupported hardware settings.
It must report readback/effective settings before data, never silently round.

Enabled IMUs require acceleration_range_g (2, 4, 8 or 16) and
angular_rate_range_dps (125, 250, 500, 1000 or 2000). Legacy SCL3300 requires tilt_mode
1–4. RM3100 requires each XYZ cycle count in 1–65535; timing limits still apply.
Pressure requires the actual part number and finite pressure_min_pa <
pressure_max_pa from that part's transfer function. MAX-M10S uses the period
and the fixed NAV-PVT payload profile. Configuration fields belonging to another
sensor are invalid. Optional register_config contains at most 32 sorted, unique
8-bit address/value pairs for LSM6DSO or RM3100; it is empty for other models.
Driver-specific bus setup and filter controls must be captured by the eventual
adapter configuration/recording metadata before hardware acquisition is qualified.

## Time, ordering and loss

Timestamp.domain is PI_MONOTONIC_RAW for IDs 1–6 and 9, and MCU_MONOTONIC for
ID 7. Pressure ID 8 uses PI_MONOTONIC_RAW on DAQHAT-01 and retains MCU_MONOTONIC
for legacy USB-head recordings. Session validation binds the pressure clock to
the advertised board identity. Field layouts and the Buf baseline are unchanged.
acquisition_ns is required with explicit presence: zero is a valid timestamp.
MCU ticks are extended through timer wraps before conversion to nanoseconds;
a reset begins a new boot/session. No timestamp wraps or decreases within a
session. MCU time and Pi monotonic time have unrelated origins and rates.
Report uncertainty_ns only when bounded; absent means unknown. Resolution is
not accuracy. For polled/FIFO devices, include readout/sample-age uncertainty.

UTC is an optional correlated estimate with an explicit utc_uncertainty_ns.
Neither UTC field may appear alone. POSIX UTC nanoseconds exclude leap seconds;
omit the estimate when the leap-second mapping/correlation is ambiguous.
The Pi must retain the original acquisition time and later record its correlation
and arrival time separately. USB arrival time cannot populate acquisition_ns.
For GNSS, the Pi acquisition timestamp describes capture of the NAV-PVT message;
the actual navigation epoch and fix flags remain in NAV-PVT. A VALID sample
does **not** mean that NAV-PVT reports a valid position or UTC fix.

Sequence is an explicit uint64 per sensor and boot, starting at zero; zero must
be encoded with presence. It advances for every accounted acquisition slot,
including known failed/dropped slots. A batch has 1–4 samples from one sensor,
one configuration and one clock. Within a batch sequences are consecutive and
acquisition times strictly increase. Split batches at a known loss, reset or
configuration change. Exhausting uint64 starts a new session, never wraps.

dropped_before is the number of known discarded slots before this batch since
the prior batch, including initial discard. Explicit zero means none; absence
means unknown. It cannot exceed the first sequence. A missing placeholder already
occupies a sequence slot and must not also be counted as discarded. Unknown FIFO
loss needs BUFFER_OVERFLOW status and absent loss count, never a fabricated zero.
Receivers must enforce cross-batch ordering, configuration and reset epochs in
the acquisition layer (step 2); the current validator is stateless.

Quality is required. VALID and SATURATED retain raw measurements. MISSING has
neither raw nor calibrated values; its timestamp is the scheduled/estimated slot
with honest uncertainty. FAULT retains a captured but suspect raw response and
has no calibrated values; a failed read without bytes is MISSING plus IO_ERROR.
Pressure responses with non-normal sensor status cannot be labeled VALID or
SATURATED. Status may target one sensor or zero for the producer. Status detail
is at most 96 UTF-8 bytes with no control characters. Optional dropped_total is
a cumulative known loss count for the current sensor/boot, not a reset counter.

## Calibrated values

Raw values are always retained. Calibrated doubles are optional, finite, in SI:
m/s², rad/s, rad, tesla, pascal and kelvin. Temperature cannot be below 0 K.
Vectors require all three axes, including explicit zeroes. Values remain in
sensor package axes; no implicit rotation into geographic or HAT axes occurs.
Calibration requires a nonempty calibration_id naming immutable coefficients,
units, method and provenance stored with recordings by the acquisition layer.
No anonymous/default calibration is permitted. Calibrated values are allowed
only for VALID/SATURATED samples and must match the sensor kind. GNSS is kept
losslessly as NAV-PVT in this revision; position/fix decoding is later work.

## USB CDC framing and bounds

Protobuf does not define byte-stream boundaries. A frame is:

1. Serialize one Envelope, **1–1024 bytes**.
2. Append CRC-32/ISO-HDLC of that payload as four little-endian bytes.
   Parameters: reflected polynomial 0xEDB88320, initial/xorout 0xFFFFFFFF;
   the check value for ASCII `123456789` is 0xCBF43926.
3. COBS-encode payload plus CRC and append a zero delimiter.

Maximum decoded length is 1028, encoded length is 1033 and wire length including
delimiter is 1034 bytes. Send an initial zero when opening a stream. Ignore empty
delimiters. Check length, COBS and CRC **before** Protobuf decoding, then apply
semantic validation. A sample-count limit never overrides the payload-byte
limit; split batches as needed. These bounds apply equally to recordings.

On corruption, drop that frame, increment a visible error counter and resume at
the next delimiter. On overflow, discard without buffering until a delimiter.
Disconnect resets partial framing state and requires identity/configuration
again. A partial frame without a delimiter is bounded but needs a transport
timeout in the transport layer (implemented as one second). The decoder yields
frames rather than accumulating an
unbounded list. Its caller must exhaust each feed iterator and use a bounded
dispatch queue. CRC detects accidental corruption; it is not authentication.

## MCU feasibility and remaining gates

The STM32F042K6 has **6 KiB SRAM and 32 KiB flash**. Nanopb is the candidate C
codec because bounded fields can use static allocations; proposed bounds are in
[sensor.options](../sw/interfaces/proto/groundlark/sensor/v1/sensor.options).
One RX encoded buffer (1033 bytes), one TX buffer (1034 bytes), and a provisional
2048-byte cap for decoded messages total **4115 bytes**, leaving **2029 bytes**
for USB state, sensor queues, stack and other globals. This is a tight budget,
not a measured fit or a firmware selection. Prefer in-place RX decoding and
streamed TX/one message at a time; do not queue decoded Envelopes on the MCU.

Before selecting Nanopb, generate/compile the C codec, check ARM structure sizes,
link the actual USB stack, enforce RAM/flash limits and measure stack high-water
marks under reconnect/overflow. If it does not fit, stream batch elements or
reduce the head's batch cap; do not silently truncate data. The Python reference
implementation and options file do not prove C interoperability or MCU fit.

Implemented checks include a manually specified binary producer fixture,
signed-count boundaries, missing/zero distinction, all eight sensor payloads,
timestamp/sequence rules, corruption, arbitrary frame splits, resynchronization,
overflow, and a deliberate incompatible schema change rejected by Buf.
The [acquisition layer](sensor-software.md) implements cross-batch state,
bounded recovery, calibration artifacts, recording/replay and modeled/Linux
adapters. Polling leaves conversion uncertainty and physical loss unknown.
USB enumeration, MCU firmware and physical testing remain open.

References: [Protobuf presence](https://protobuf.dev/programming-guides/field_presence/),
[Buf breaking checks](https://buf.build/docs/reference/cli/buf/breaking/),
[Nanopb allocation bounds](https://jpa.kapsi.fi/nanopb/docs/concepts.html),
[STM32F042 datasheet](https://www.st.com/resource/en/datasheet/stm32f042t6.pdf),
[LSM6DSO](https://www.st.com/en/mems-and-sensors/lsm6dso.html),
[SCL3300](https://www.murata.com/-/media/webrenewal/products/sensor/pdf/datasheet/datasheet_scl3300-d01.ashx).

## Burrowlark enclosure climate

Sensor ID **17**, SHT45 U6, belongs only to the USB head (board kind 2), alongside
RM3100 ID 7. It uses the existing `ClimateRaw` message with six original response
bytes and both valid Sensirion CRCs. Acquisition timestamps use the MCU monotonic
domain. Its only supported enabled profile is high precision, heater off,
1,000,000,000 ns publication period with no additional configuration fields.
Temperature/humidity display conversion is the same as SHT40 ID 15. Keep raw
precision and explicit missing/unknown values. Existing magnetometer-only
recordings remain valid; absence of sensor 17 is not a zero climate reading.

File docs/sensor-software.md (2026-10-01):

# Sensor acquisition and recovery

For `calibration-observe`, `calibration-fit`, measured reference templates and instrument-bound calibration records, see [Calibrating Groundlark](calibration.md).

**New to the simulator?** Start with the [browser workbench walkthrough](sensor-workbench.md).
This page covers command-line development and real Linux acquisition.
The current HAT has three IMUs, a Racotech geophone input, infrasound and MAX-M10S GNSS. The fourth IMU and inclinometer remain legacy-only.
DLVR infrasound is covered by simulation and the six-sensor browser bench;
its Pi I2C hardware driver remains pending. The live factory currently supports
the IMUs, geophone ADC and GNSS receiver.

The runnable Pi application is in `sw/pi/groundlark/`; use
`sw/tools/sensor.py` as its repository entry point. It has no FPGA,
network service or database dependency. Simulation and Linux device adapters
use the same scheduler, calibration, session validation and recording path.
Physical acceptance follows the [bench procedure](bench-procedure.md).

## Run without hardware

Run `./lab.ps1 test -Profile software` (or `sh ./lab.sh test --profile software`).
The portable environment contains the pinned Python/Protobuf and Buf tools.
It builds the descriptor, runs tests, executes a two-second six-sensor fault
scenario and replays it. Retained outputs are under
`.lab/runs/<run-id>/results/sw/build/`: `demo.ssrec`, `demo-summary.json` and
`verification.json`. Five-run retention and existing cleanup cover these files.
No new environment or global package installation is needed for this workflow.

For direct development use Python 3.12+ with the Protobuf version in
`environment/requirements.lock`, and Buf 1.73.0. Generate the descriptor once:

```sh
mkdir -p sw/build
buf build sw/interfaces --exclude-source-info -o sw/build/schema.binpb
python sw/tools/sensor.py simulate --remote --seconds 2 \
  --faults sw/tests/fixtures/acquisition_faults.json --output sw/build/my-run.ssrec
python sw/tools/sensor.py replay sw/build/my-run.ssrec
```

Outputs use exclusive creation: choose a new filename for each direct run.
The lab manages its own copy and does not delete direct developer recordings.
`GROUNDLARK_DESCRIPTOR` can select a descriptor outside the default build
directory. Do not use the frozen compatibility baseline as the generated schema.

The scenario is deterministic for a given seed, configuration and fault file,
including recording bytes. It covers three IMUs, geophone,
magnetometer and pressure. Remote streams in this command are modeled MCU
producers, not firmware or USB emulation. Separate tests send framed messages
in fragments through a Linux pseudo-terminal. `--queue 1 --drain-every 100`
exercises a slow consumer. Simulated time starts at zero; Pi and remote clocks
retain distinct domains even when numerically equal.

Virtual sensors use controllable motion, magnetic, pressure and geophone
[stimulus models](stimulus-models.md). Pass `--scenario` for saved waveforms and
timed controls; `export-scenario` recovers controls from a recording. Without a
scenario, sensors start stationary and level, with a constant magnetic field,
zero differential pressure and zero geophone velocity.

## Linux device adapters

The live path uses Linux SPI/I²C ioctls, GPIO character-device line requests,
and a nonblocking USB CDC TTY. The initial profile is:

| Sensor | Configuration and reading |
| --- | --- |
| Three LSM6DSO | 26 Hz, ±2 g, ±250 dps; identity/reset/readback; BDU/address increment; signed temperature, gyro and acceleration. |
| MAX-M10S-00B | I²C 0x42, 1 Hz NAV-PVT; optional timing configuration/readback, TIM-TP, NAV-TIMEUTC and BCM24 PPS capture. |
| ADS122C04 geophone input | I²C 0x40; 330 SPS, PGA64, internal 2.048 V reference; signed 24-bit counts, conversion counter and inverted-data integrity checks. |
| Burrowlark DAQUSB-01 USB head | Receive v1 identity/configuration/batches/status over framed CDC; real firmware is still required. |

IMU filter registers are explicitly written, checked and included in effective
`register_config`. The default 26 Hz profile has 13 Hz accelerometer and 8.3 Hz
gyro bandwidth; sample rate is not flat signal bandwidth. See
[sensor bandwidth and timing](sensor-response.md) for both boards' response and
aliasing limits. Raw samples and existing timestamp uncertainty remain intact.

SCL3300 is retained for legacy recordings. MAX-M10S is active at I2C address 0x42; add `--fifo --utc` to capture timing evidence and BCM24 PPS.

Copy [the example profile](../sw/pi/profiles/daqhat-01.example.json) and verify paths
on the actual Pi. `gpiochip0` is an example, not an assertion about Pi 5 GPIO
numbering. `line` is the character-device offset corresponding to BCM26 on that
chip. The application owns active-low sensor output enable and disables it on
normal/error cleanup.

| Signal | BCM GPIO | Physical header pin |
| --- | --- | --- |
| SPI0 MOSI / MISO / SCLK | 10 / 9 / 11 | 19 / 21 / 23 |
| IMU1 / IMU2 / IMU3 chip select | 8 / 7 / 5 | 24 / 26 / 29 |
| Supervisor shutdown request / halt acknowledgement | 6 / 13 | 31 / 33 |
| GNSS TIMEPULSE | 24 | 18 |
| Sensor buffer OE, active low | 26 | 37 |
| Geophone ADC I²C SDA / SCL | 2 / 3 | 3 / 5 |

The [Pi 4 deployment package](../sw/pi/deploy/README.md) now supplies the three-CS
overlay, 100 kHz I²C configuration and an identity-checked `driver_override`
binding tool. Its compiled overlay is merge-tested in the portable lab. The
selected physical Pi/kernel must still be boot-tested. No overlay is installed
automatically and no unrelated kernel device is detached.

```sh
python sw/tools/sensor.py live --profile sw/pi/profiles/daqhat-01.example.json \
  --seconds 60 --output sw/build/bench-001.ssrec
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

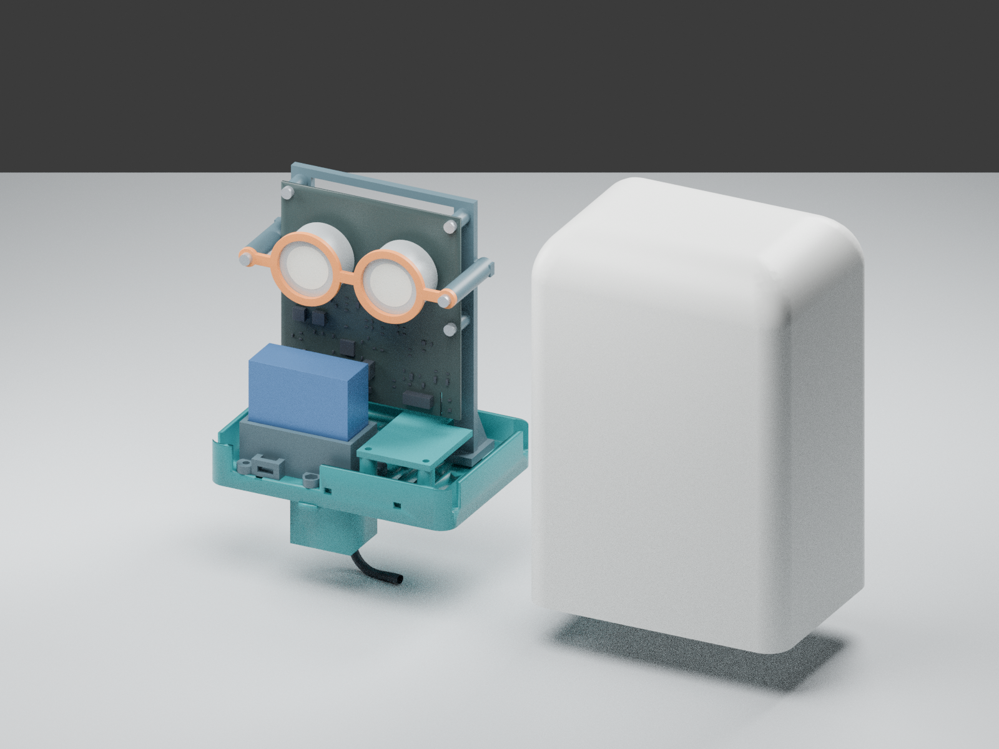
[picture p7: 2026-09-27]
hw/skylark-usb/mechanical/bell/preview/open.png

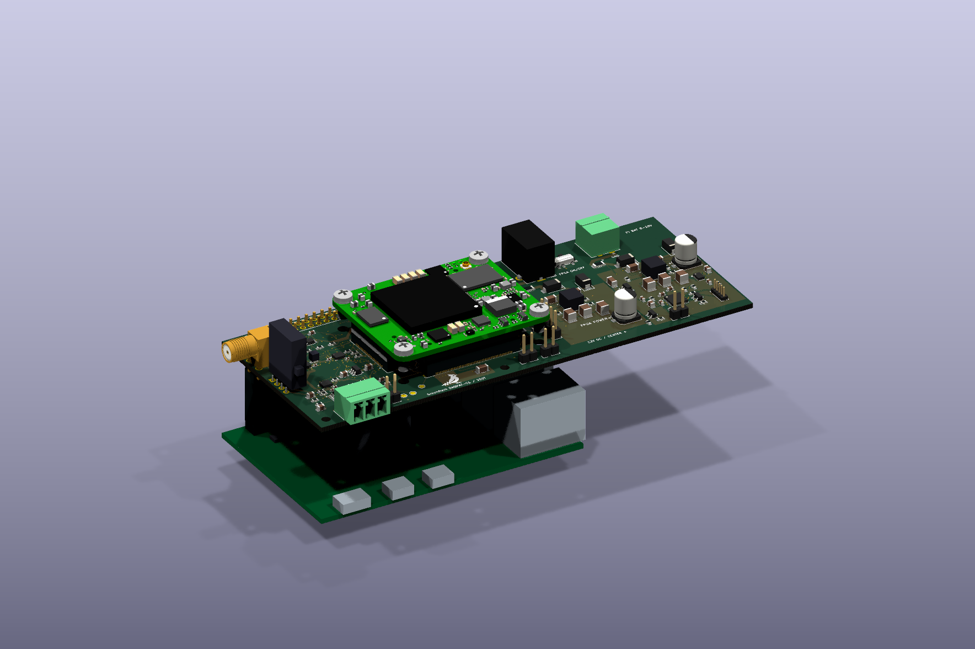
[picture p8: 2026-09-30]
hw/groundlark-fpga-hat/boards/groundlark-daqhat-01/pi-trenz-stack-concept.png

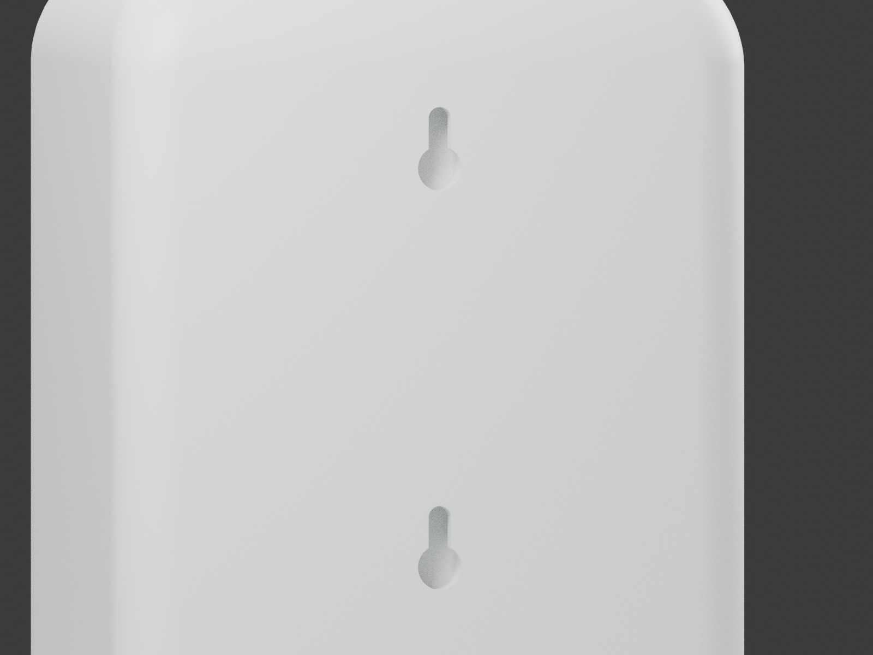
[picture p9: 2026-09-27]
hw/skylark-usb/mechanical/bell/preview/rear-detail.png

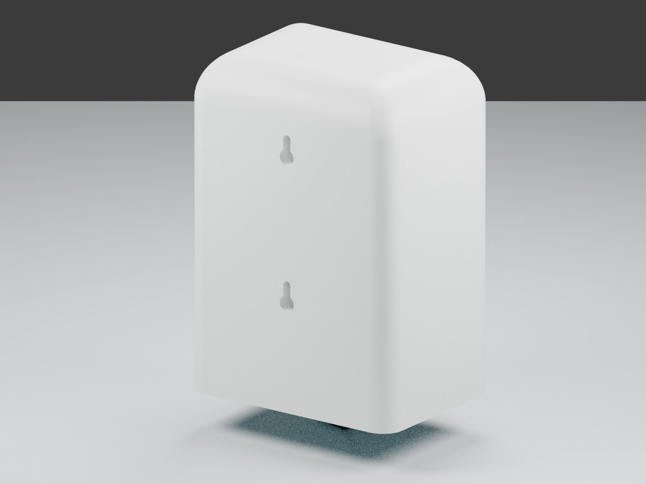
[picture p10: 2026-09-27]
hw/skylark-usb/mechanical/bell/preview/rear.png

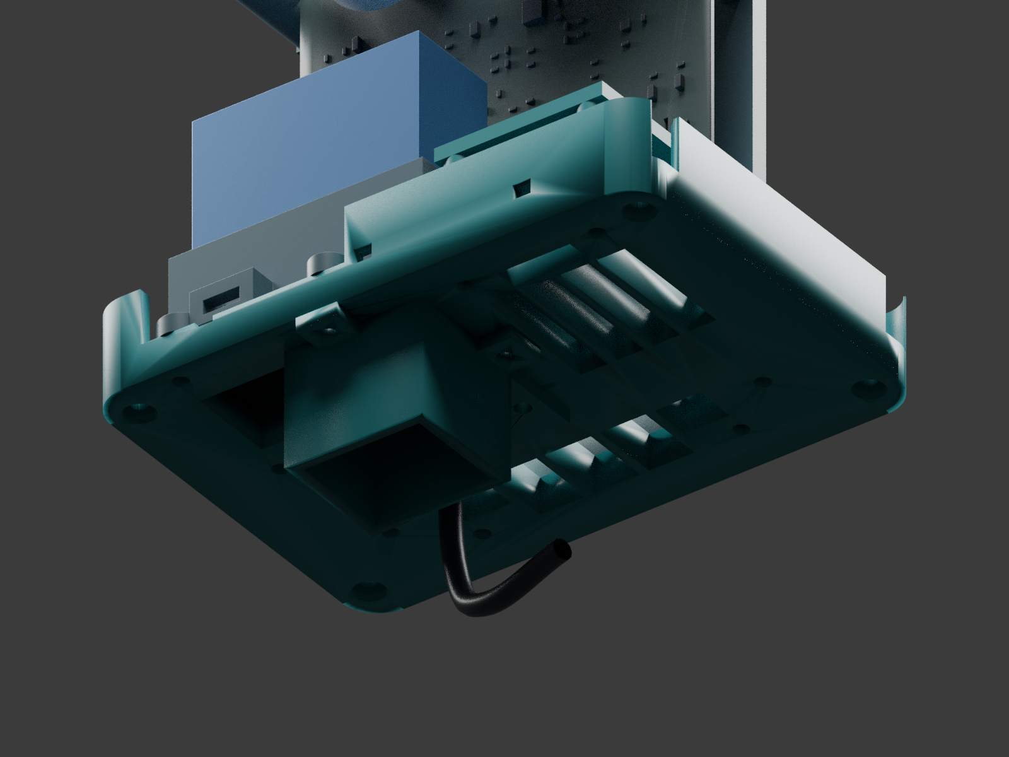
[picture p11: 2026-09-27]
hw/skylark-usb/mechanical/bell/preview/bottom-vents.png

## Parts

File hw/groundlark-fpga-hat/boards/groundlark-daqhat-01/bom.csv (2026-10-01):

Reference | Value | MPN | Footprint | DNP | Note
J1 | Raspberry Pi 40-pin | Samtec ESQ-120-23-G-D | Connector_PinHeader_2.54mm__PinHeader_2x20_P2.54mm_Vertical | False | Header land pattern matches bottom mounted socket top-view numbering; tall stack, check Pi 4/5 cooler clearance.
U1 | 24LC32A | 24LC32A-I/SN | Package_SO__SOIC-8_3.9x4.9mm_P1.27mm | False
R1 | 3.9k | RC0603FR-073K9L | Resistor_SMD__R_0603_1608Metric | False
R2 | 3.9k | RC0603FR-073K9L | Resistor_SMD__R_0603_1608Metric | False
R3 | 1k | RC0603FR-071KL | Resistor_SMD__R_0603_1608Metric | False
JP1 | EEPROM write enable | EEPROM write enable | Connector_PinHeader_2.54mm__PinHeader_1x02_P2.54mm_Vertical | False | Fit shunt only while programming ID EEPROM.
C1 | 100n | GRM188R71H104KA93D | Capacitor_SMD__C_0603_1608Metric | False
C2 | 10u | GRM21BR61A106KE19L | Capacitor_SMD__C_0805_2012Metric | False
C3 | 10u | GRM21BR61A106KE19L | Capacitor_SMD__C_0805_2012Metric | False
U11 | LSM6DSOTR | LSM6DSOTR | Package_LGA__LGA-14_3x2.5mm_P0.5mm_LayoutBorder3x4y | False
C12 | 100n | GRM155R71C104KA88D | Capacitor_SMD__C_0402_1005Metric | False
C13 | 100n | GRM155R71C104KA88D | Capacitor_SMD__C_0402_1005Metric | False
R11 | 10k | RC0603FR-0710KL | Resistor_SMD__R_0603_1608Metric | False
U12 | LSM6DSOTR | LSM6DSOTR | Package_LGA__LGA-14_3x2.5mm_P0.5mm_LayoutBorder3x4y | False
C14 | 100n | GRM155R71C104KA88D | Capacitor_SMD__C_0402_1005Metric | False
C15 | 100n | GRM155R71C104KA88D | Capacitor_SMD__C_0402_1005Metric | False
R12 | 10k | RC0603FR-0710KL | Resistor_SMD__R_0603_1608Metric | False
U13 | LSM6DSOTR | LSM6DSOTR | Package_LGA__LGA-14_3x2.5mm_P0.5mm_LayoutBorder3x4y | False
C16 | 100n | GRM155R71C104KA88D | Capacitor_SMD__C_0402_1005Metric | False
C17 | 100n | GRM155R71C104KA88D | Capacitor_SMD__C_0402_1005Metric | False
R13 | 10k | RC0603FR-0710KL | Resistor_SMD__R_0603_1608Metric | False
J4 | FPGA test UART/reset | FPGA UART service ONLY | Connector_PinHeader_2.54mm__PinHeader_1x04_P2.54mm_Vertical | False | Test points for assembled module UART and active-low reset; do not connect a second driving host.
H1 | M2.5 NPTH | M2.5 NPTH | MountingHole__MountingHole_2.7mm_M2.5 | False | Nonmagnetic standoffs.
H2 | M2.5 NPTH | M2.5 NPTH | MountingHole__MountingHole_2.7mm_M2.5 | False | Nonmagnetic standoffs.
H3 | M2.5 NPTH | M2.5 NPTH | MountingHole__MountingHole_2.7mm_M2.5 | False | Nonmagnetic standoffs.
H4 | M2.5 NPTH | M2.5 NPTH | MountingHole__MountingHole_2.7mm_M2.5 | False | Nonmagnetic standoffs.
U40 | TLV1117LV33DCYR | TLV1117LV33DCYR | Package_TO_SOT_SMD__SOT-223-3_TabPin2 | False
C40 | 10u | GRM21BR61A106KE19L | Capacitor_SMD__C_0805_2012Metric | False
C41 | 100n | GRM188R71H104KA93D | Capacitor_SMD__C_0603_1608Metric | False
C42 | 22u | GRM31CR61A226KE19L | Capacitor_SMD__C_1206_3216Metric | False
C43 | 100n | GRM188R71H104KA93D | Capacitor_SMD__C_0603_1608Metric | False
U41 | SN74LVC8T245PWR | SN74LVC8T245PWR | Package_SO__TSSOP-24_4.4x7.8mm_P0.65mm | False
U42 | SN74LVC8T245PWR | SN74LVC8T245PWR | Package_SO__TSSOP-24_4.4x7.8mm_P0.65mm | False
C44 | 100n | GRM188R71H104KA93D | Capacitor_SMD__C_0603_1608Metric | False
C45 | 100n | GRM188R71H104KA93D | Capacitor_SMD__C_0603_1608Metric | False
C46 | 100n | GRM188R71H104KA93D | Capacitor_SMD__C_0603_1608Metric | False
C47 | 100n | GRM188R71H104KA93D | Capacitor_SMD__C_0603_1608Metric | False
R50 | 10k | RC0603FR-0710KL | Resistor_SMD__R_0603_1608Metric | False
R51 | 100k | RC0603FR-07100KL | Resistor_SMD__R_0603_1608Metric | False
U43 | ISO1640BDR | ISO1640BDR | Package_SO__SOIC-8_3.9x4.9mm_P1.27mm | False | Power-domain isolation only: grounds are joined. Side-1 VOL max 0.71V requires host VIL >=0.8V; verify Pi revision.
C48 | 100n | GRM188R71H104KA93D | Capacitor_SMD__C_0603_1608Metric | False
C49 | 100n | GRM188R71H104KA93D | Capacitor_SMD__C_0603_1608Metric | False
R52 | 4.7k | RC0603FR-074K7L | Resistor_SMD__R_0603_1608Metric | False
R53 | 4.7k | RC0603FR-074K7L | Resistor_SMD__R_0603_1608Metric | False
TP1 | SENS_3V3 | SENS_3V3 | TestPoint__TestPoint_Pad_D1.5mm | False
TP2 | GND | GND | TestPoint__TestPoint_Pad_D1.5mm | False
TP4 | SENSOR_OE_N | SENSOR_OE_N | TestPoint__TestPoint_Pad_D1.5mm | False
U51 | TXU0202DCUR | TXU0202DCUR | Package_SO__VSSOP-8_2.3x2mm_P0.5mm | False
C75 | 100n | GRM188R71H104KA93D | Capacitor_SMD__C_0603_1608Metric | False
C76 | 100n | GRM188R71H104KA93D | Capacitor_SMD__C_0603_1608Metric | False
R61 | 47 | RC0603FR-0747RL | Resistor_SMD__R_0603_1608Metric | False
R62 | 100k | RC0603FR-07100KL | Resistor_SMD__R_0603_1608Metric | False
R63 | 10k | RC0603FR-0710KL | Resistor_SMD__R_0603_1608Metric | False
U52 | TLV803EA30DBZR | TLV803EA30DBZR | Package_TO_SOT_SMD__SOT-23 | False | 3.0V falling threshold, 200ms nominal release delay; open-drain output.
C77 | 100n | GRM188R71H104KA93D | Capacitor_SMD__C_0603_1608Metric | False
R64 | 10k | RC0603FR-0710KL | Resistor_SMD__R_0603_1608Metric | False
Q1 | 2N7002 | 2N7002 | Package_TO_SOT_SMD__SOT-23 | False | Pi GPIO17 HIGH asserts chip reset; does not drive a live voltage into unpowered chip.
R65 | 1k | RC0603FR-071KL | Resistor_SMD__R_0603_1608Metric | False
R66 | 100k | RC0603FR-07100KL | Resistor_SMD__R_0603_1608Metric | False
J80 | LSHM-150-04.0-L-DV-A-S-K-TR | LSHM-150-04.0-L-DV-A-S-K-TR | TZ_TZ100 | False | Mates JM1; opposite parity; 8 mm board surface gap
J81 | LSHM-150-04.0-L-DV-A-S-K-TR | LSHM-150-04.0-L-DV-A-S-K-TR | TZ_TZ100 | False | Mates JM2; opposite parity; 8 mm board surface gap
J82 | LSHM-130-04.0-L-DV-A-S-K-TR | LSHM-130-04.0-L-DV-A-S-K-TR | TZ_TZ60 | False | Mates JM3; opposite parity; 8 mm board surface gap
JP80 | TSW-102-07-G-S | TSW-102-07-G-S | TZ_TZ_JP | False | Fit shunt to DISABLE module; open enables on-board sequence
JP81 | TSW-102-07-G-S | TSW-102-07-G-S | TZ_TZ_JP | False | Fit shunt to request module configuration reset
R80 | 10k | RC0603FR-0710KL | Resistor_SMD__R_0603_1608Metric | False | FPGA JTAG selection / spare CPLD control idle pull-down
R81 | 10k | RC0603FR-0710KL | Resistor_SMD__R_0603_1608Metric | False | FPGA JTAG selection / spare CPLD control idle pull-down
C80 | 22u | GRM31CR61A226KE19L | Capacitor_SMD__C_1206_3216Metric | False | Carrier local decoupling; module contains core decoupling
C81 | 22u | GRM31CR61A226KE19L | Capacitor_SMD__C_1206_3216Metric | False | Carrier local decoupling; module contains core decoupling
C82 | 22u | GRM31CR61A226KE19L | Capacitor_SMD__C_1206_3216Metric | False | Carrier local decoupling; module contains core decoupling
C83 | 100n | GRM188R71H104KA93D | Capacitor_SMD__C_0603_1608Metric | False | Carrier local decoupling; module contains core decoupling
C84 | 4.7u | GRM21BR71A475KA73L | Capacitor_SMD__C_0805_2012Metric | False | Carrier local decoupling; module contains core decoupling
C85 | 4.7u | GRM21BR71A475KA73L | Capacitor_SMD__C_0805_2012Metric | False | Carrier local decoupling; module contains core decoupling
H80 | M3 / 8 mm spacer | M3 / 8 mm spacer | TZ_TZ_HOLE | False
H81 | M3 / 8 mm spacer | M3 / 8 mm spacer | TZ_TZ_HOLE | False
H82 | M3 / 8 mm spacer | M3 / 8 mm spacer | TZ_TZ_HOLE | False
H83 | M3 / 8 mm spacer | M3 / 8 mm spacer | TZ_TZ_HOLE | False
U22 | ADS122C04 | ADS122C04IPWR | Package_SO__TSSOP-16_4.4x5mm_P0.65mm | False | I2C 0x40; internal 2.048V reference, gain 64, normal 330 SPS; unused analog/reference inputs open per TI.
J90 | GEO + / - / SHIELD | 1803280 | Connector_Phoenix_MC__PhoenixContact_MC_1,5_3-G-3.81_1x03_P3.81mm_Horizontal | False | Horizontal outward entry (+Y). 1 positive, 2 negative, 3 cable shield. Mate Phoenix 1803581. Never connect power.
D90 | TPD2E2U06 | TPD2E2U06DCKR | Package_TO_SOT_SMD__SOT-323_SC-70 | False | Connector ESD suppression only; not lightning protection.
R90 | 1k | RC0603FR-071KL | Resistor_SMD__R_0603_1608Metric | False | Matched series input filter / current limiting.
R91 | 1k | RC0603FR-071KL | Resistor_SMD__R_0603_1608Metric | False
C90 | 100n C0G | C3216C0G1H104J160AA | Capacitor_SMD__C_1206_3216Metric | False | C0G differential filter; no piezoelectric X7R on signal path.
C91 | 1n C0G | C0603C102J5GACTU | Capacitor_SMD__C_0603_1608Metric | False
C92 | 1n C0G | C0603C102J5GACTU | Capacitor_SMD__C_0603_1608Metric | False
R92 | 1M | RC0603FR-071ML | Resistor_SMD__R_0603_1608Metric | False
R93 | 1M | RC0603FR-071ML | Resistor_SMD__R_0603_1608Metric | False
R94 | 10k | RC0603FR-0710KL | Resistor_SMD__R_0603_1608Metric | False
R95 | 10k | RC0603FR-0710KL | Resistor_SMD__R_0603_1608Metric | False
C93 | 10u | GRM21BR61A106KE19L | Capacitor_SMD__C_0805_2012Metric | False | Filtered mid-supply; sensor has no excitation current source.
R96 | 22 | RC0603FR-0722RL | Resistor_SMD__R_0603_1608Metric | False
C94 | 10u | GRM21BR61A106KE19L | Capacitor_SMD__C_0805_2012Metric | False
C95 | 100n | GRM188R71H104KA93D | Capacitor_SMD__C_0603_1608Metric | False
C96 | 100n | GRM188R71H104KA93D | Capacitor_SMD__C_0603_1608Metric | False
R97 | 10k | RC0603FR-0710KL | Resistor_SMD__R_0603_1608Metric | False | Open-drain DRDY pullup; existing U42 return buffer to BCM4.
U100 | TMUX1574PWR | TMUX1574PWR | Package_SO__TSSOP-16_4.4x5mm_P0.65mm | False | SEL=0 application, SEL=1 native JTAG; EN high isolates; FPGA-powered with power-off protection.
U101 | TMUX1574PWR | TMUX1574PWR | Package_SO__TSSOP-16_4.4x5mm_P0.65mm | False | S1B/S2B deliberately open parking paths: isolate CS/DQ3 in JTAG. Unused complete channels grounded.
U102 | TCA9534PWR | TCA9534PWR | Package_SO__TSSOP-16_4.4x5mm_P0.65mm | False | I2C 0x20. Write output 0 before config 0xFC. P2-P7 remain grounded inputs; INT unused. Pi header supplies I2C pullups.
U103 | SN74LVC1G10DCKR | SN74LVC1G10DCKR | Package_TO_SOT_SMD__SOT-363_SC-70-6 | False | Disable unless request AND both independent rail supervisors are high; inputs tolerate an unpowered gate.
U104 | TLV809EA30DBZR | TLV809EA30DBZR | Package_TO_SOT_SMD__SOT-23 | False | 3.0 V threshold, 200 ms nominal release, push-pull. Separate from application reset.
U105 | TLV809EA30DBZR | TLV809EA30DBZR | Package_TO_SOT_SMD__SOT-23 | False | 3.0 V threshold, 200 ms nominal release, push-pull. Separate from application reset.
C100 | 100n | GRM188R71H104KA93D | Capacitor_SMD__C_0603_1608Metric | False
C101 | 100n | GRM188R71H104KA93D | Capacitor_SMD__C_0603_1608Metric | False
C102 | 100n | GRM188R71H104KA93D | Capacitor_SMD__C_0603_1608Metric | False
C103 | 100n | GRM188R71H104KA93D | Capacitor_SMD__C_0603_1608Metric | False
C104 | 100n | GRM188R71H104KA93D | Capacitor_SMD__C_0603_1608Metric | False
C105 | 100n | GRM188R71H104KA93D | Capacitor_SMD__C_0603_1608Metric | False
R100 | 22 | RC0603FR-0722RL | Resistor_SMD__R_0603_1608Metric | False | 22 ohm series damping; quad data paths are bidirectional. Qualify maximum clock on hardware.
R101 | 22 | RC0603FR-0722RL | Resistor_SMD__R_0603_1608Metric | False | 22 ohm series damping; quad data paths are bidirectional. Qualify maximum clock on hardware.
R102 | 22 | RC0603FR-0722RL | Resistor_SMD__R_0603_1608Metric | False | 22 ohm series damping; quad data paths are bidirectional. Qualify maximum clock on hardware.
R103 | 22 | RC0603FR-0722RL | Resistor_SMD__R_0603_1608Metric | False | 22 ohm series damping; quad data paths are bidirectional. Qualify maximum clock on hardware.
R104 | 22 | RC0603FR-0722RL | Resistor_SMD__R_0603_1608Metric | False | 22 ohm series damping; quad data paths are bidirectional. Qualify maximum clock on hardware.
R105 | 22 | RC0603FR-0722RL | Resistor_SMD__R_0603_1608Metric | False | 22 ohm series damping; quad data paths are bidirectional. Qualify maximum clock on hardware.
R106 | 10k | RC0603FR-0710KL | Resistor_SMD__R_0603_1608Metric | False
R107 | 10k | RC0603FR-0710KL | Resistor_SMD__R_0603_1608Metric | False
R108 | 10k | RC0603FR-0710KL | Resistor_SMD__R_0603_1608Metric | False
R109 | 10k | RC0603FR-0710KL | Resistor_SMD__R_0603_1608Metric | False
R110 | 10k | RC0603FR-0710KL | Resistor_SMD__R_0603_1608Metric | False
R111 | 10k | RC0603FR-0710KL | Resistor_SMD__R_0603_1608Metric | False
R112 | 100k | RC0603FR-07100KL | Resistor_SMD__R_0603_1608Metric | False
R113 | 10k | RC0603FR-0710KL | Resistor_SMD__R_0603_1608Metric | False
R114 | 100k | RC0603FR-07100KL | Resistor_SMD__R_0603_1608Metric | False
R115 | 10k | RC0603FR-0710KL | Resistor_SMD__R_0603_1608Metric | False
R116 | 100k | RC0603FR-07100KL | Resistor_SMD__R_0603_1608Metric | False
R117 | 100k | RC0603FR-07100KL | Resistor_SMD__R_0603_1608Metric | False
U106 | SN74LVC1G08DCKR | SN74LVC1G08DCKR | Package_TO_SOT_SMD__SOT-353_SC-70-5 | False | Existing BCM25 FPGA_IO_ENABLE is also a hardware disarm independent of I2C. Default-low R62 retained.
C106 | 100n | GRM188R71H104KA93D | Capacitor_SMD__C_0603_1608Metric | False
U23 | DLVR-F50D | DLVR-F50D-E1BS-I-NI3F | Groundlark__DLVR_E1BS | False | Fitted 3.3 V I2C 0x28; pneumatic response and thermal/vibration isolation require qualification.
C24 | 100n | GRM188R71H104KA93D | Capacitor_SMD__C_0603_1608Metric | False | Local DLVR supply bypass
J83 | 12V DC / CENTER + | PJ-102AH | PWR_BarrelJack_CUI_PJ-102AH_Horizontal | False | 5.5/2.1 mm mating plug; mouth faces -Y, opposite J90 +Y; sleeve switch pin 3 NC
F80 | 0466002.NRHF | 0466002.NRHF | PWR_Fuse_1206_3216Metric | False | Input fuse; output current controlled by buck converter
D80 | B340A | B340A-13-F | PWR_D_SMA | False | 3 A / 40 V Schottky; reverse-polarity series protection
D81 | SMAJ15A | SMAJ15A-13-F | PWR_D_SMA | False | 15 V standoff TVS; transient suppression, not sustained overvoltage cutoff
U80 | TPSM53603 | TPSM53603RDAR | PWR_Texas_B3QFN-14-1EP_5x5.5mm_P0.65mm | False | Pins 4/5 DNC isolated; pin13 V5V NC; 3 A envelope, thermal qualification pending
R120 | 10k | RT0603BRD0710KL | PWR_R_0603_1608Metric | False | 0.1% feedback upper
R121 | 4.30k | RT0603BRD074K3L | PWR_R_0603_1608Metric | False | 0.1% feedback lower; nominal 3.32558 V
R122 | 100k | RC0603FR-07100KL | PWR_R_0603_1608Metric | False | UVLO upper
R123 | 15k | RC0603FR-0715KL | PWR_R_0603_1608Metric | False | UVLO lower
R124 | 10k | RT0603BRD0710KL | PWR_R_0603_1608Metric | False | Power-good pullup; module sequencing inhibited until converter PGOOD
SW80 | FPGA OFF / ON | PCM12SMTR | PWR_SW_SPDT_PCM12 | False | OFF grounds converter EN; ON leaves divider active; no Pi required
C86 | 10u | CGA5L1X7R1H106K160AC | PWR_C_1206_3216Metric | False | 50 V X7R 1206; TI recommended input capacitor
C87 | 10u | CGA5L1X7R1H106K160AC | PWR_C_1206_3216Metric | False | 50 V X7R 1206; TI recommended input capacitor
C88 | 100n | GRM188R71H104KA93D | PWR_C_0603_1608Metric | False | 50 V ceramic input bypass
C89 | 47u | EEE-FK1V470P | PWR_CP_Elec_6.3x7.7 | False | 35 V aluminum input bulk; observe polarity
C110 | 22u | GRM32ER71E226KE15L | PWR_C_1210_3225Metric | False | 25 V X7R 1210; three local caps must provide >=43 uF effective combined
C111 | 22u | GRM32ER71E226KE15L | PWR_C_1210_3225Metric | False | 25 V X7R 1210; three local caps must provide >=43 uF effective combined
C112 | 22u | GRM32ER71E226KE15L | PWR_C_1210_3225Metric | False | 25 V X7R 1210; three local caps must provide >=43 uF effective combined
J130 | PI BATTERY 8-18V | 1803277 | SUP_PhoenixContact_MC_1,5_2-G-3.81_1x02_P3.81mm_Horizontal | False | External protected battery/controller DC output; no solar panel or charging input
F130 | 4A fuse | 0466004.NRHF | SUP_Fuse_1206_3216Metric | False
D130 | B340A | B340A-13-F | PWR_D_SMA | False
D131 | SMAJ18A | SMAJ18A-13-F | SUP_D_SMA | False
U131 | TPS70933 | TPS70933DBVR | SUP_SOT-23-5 | False | Always on; EN internally biased, never connect EN to raw battery
C130 | 4.7u | GRM21BR71C475KA73L | SUP_C_0805_2012Metric | False | At least 2.2uF effective at 3.3V
C131 | 10u | CGA5L1X7R1H106K160AC | PWR_C_1206_3216Metric | False
U132 | TPSM53603 | TPSM53603RDAR | PWR_Texas_B3QFN-14-1EP_5x5.5mm_P0.65mm | False | 5.149V / 3A total Pi+HAT allocation; EN pulldown gives default OFF
C132 | 10u | CGA5L1X7R1H106K160AC | PWR_C_1206_3216Metric | False
C133 | 10u | CGA5L1X7R1H106K160AC | PWR_C_1206_3216Metric | False
C134 | 100n | GRM188R71H104KA93D | PWR_C_0603_1608Metric | False
C135 | 47u | EEE-FK1V470P | PWR_CP_Elec_6.3x7.7 | False
C136 | 22u | GRM32ER71E226KE15L | PWR_C_1210_3225Metric | False | Combined effective capacitance must be at least 44uF at 5.15V
C137 | 22u | GRM32ER71E226KE15L | PWR_C_1210_3225Metric | False | Combined effective capacitance must be at least 44uF at 5.15V
C138 | 22u | GRM32ER71E226KE15L | PWR_C_1210_3225Metric | False | Combined effective capacitance must be at least 44uF at 5.15V
R130 | 10k | RT0603BRD0710KL | PWR_R_0603_1608Metric | False
R131 | 2.43k | RT0603BRD072K43L | SUP_R_0603_1608Metric | False
R132 | 100k | RC0603FR-07100KL | PWR_R_0603_1608Metric | False
U133 | TPS22953 | TPS22953DQCR | SUP_Texas_WSON10_DQC0010A | False | Reverse blocking while disabled; no simultaneous Pi USB-C supply
C139 | 10n | GRM188R71H103KA01D | SUP_C_0603_1608Metric | False | 50V slew capacitor; approximately 18ms output rise
C140 | 10u | GRM21BR61C106KE15L | SUP_C_0805_2012Metric | False
R133 | 2k | RC0603FR-072KL | SUP_R_0603_1608Metric | False | Output bleed; minimum OFF time must be qualified with actual Pi capacitance
U130 | MSPM0L1106 | MSPM0L1106TRHBR | SUP_QFN-32-1EP_5x5mm_P0.5mm_EP3.45x3.45mm | False | 32k flash / 4k RAM. Internal clock; unused GPIO disabled in firmware. No external VCORE load.
C141 | 100n | GRM188R71H104KA93D | PWR_C_0603_1608Metric | False
C142 | 10u | GRM21BR61C106KE15L | SUP_C_0805_2012Metric | False
C143 | 470n | GRM188R71C474KA88D | SUP_C_0603_1608Metric | False
R134 | 47k | RC0603FR-0747KL | SUP_R_0603_1608Metric | False
C144 | 10n | GRM188R71H103KA01D | SUP_C_0603_1608Metric | False
R135 | 1M | RT0603BRD071ML | SUP_R_0603_1608Metric | False
R136 | 150k | RT0603BRD07150KL | SUP_R_0603_1608Metric | False
C145 | 10n | GRM188R71H103KA01D | SUP_C_0603_1608Metric | False
Q130 | 2N7002 | 2N7002,215 | SUP_SOT-23 | False
R137 | 100k | RC0603FR-07100KL | PWR_R_0603_1608Metric | False
R138 | 10k | RT0603BRD0710KL | PWR_R_0603_1608Metric | False
Q131 | 2N7002 | 2N7002,215 | SUP_SOT-23 | False
R139 | 100k | RC0603FR-07100KL | PWR_R_0603_1608Metric | False
R140 | 100k | RC0603FR-07100KL | PWR_R_0603_1608Metric | False
J131 | SWD / 3V3 REF | FTS-105-01-L-S | SUP_PinHeader_1x05_P1.27mm_Vertical | False | Probe voltage reference only; do not power target through header
JP130 | BENCH RUN | TSW-102-07-G-S | SUP_PinHeader_1x02_P2.54mm_Vertical | False | Open for supervised operation. Shunt is a manual run override with unprogrammed MCU; remove before firmware controls RUN.
R141 | 10k | RT0603BRD0710KL | PWR_R_0603_1608Metric | False | Limits MCU pin current if bench shunt is left fitted; remove shunt for automatic power control
TP90 | GND | PCB copper | TestPoint__TestPoint_Pad_D1.5mm | True | Calibration probe pad; no fitted component. Use high impedance probe.
TP91 | GEO_VCM | PCB copper | TestPoint__TestPoint_Pad_D1.5mm | True | Calibration probe pad; no fitted component. Use high impedance probe.
TP92 | GEO_AVDD | PCB copper | TestPoint__TestPoint_Pad_D1.5mm | True | Calibration probe pad; no fitted component. Use high impedance probe.
TP93 | GEO_DRDY_N | PCB copper | TestPoint__TestPoint_Pad_D1.5mm | True | Calibration probe pad; no fitted component. Use high impedance probe.
U21 | MAX-M10S-00B | MAX-M10S-00B | RF_GPS__ublox_MAX | False | u-blox; JLCPCB C4153167. I2C 0x42; PPS BCM24. No backup supply.
J140 | GNSS ANT / 3V3 | HL-SMA-KWE-02 | GNSS_HL_SMA_KWE_02 | False | HenryTech C20617216; female SMA 50 ohm; axis native -X. Active antenna 3.3V <=20mA. Not RP-SMA.
C146 | 4.7u | GRM21BR71C475KA73L | Capacitor_SMD__C_0805_2012Metric | False
C147 | 100n | GRM188R71H104KA93D | Capacitor_SMD__C_0603_1608Metric | False
C148 | 47p C0G | GRM1555C1H470JA01D | GNSS_C0402 | False
L140 | 27n | LQW15AN27NJ00D | GNSS_L0402 | False | 27nH wirewound RF choke; u-blox reference family. Verify impedance and RF matching on fabricated stack.
U140 | TPS70933 | TPS70933DBVR | SUP_SOT-23-5 | False | 3.3 V antenna LDO; downstream U141 limits sustained shorts to 100 mA maximum. 20 mA antenna allocation.
C149 | 4.7u | GRM21BR71C475KA73L | Capacitor_SMD__C_0805_2012Metric | False
C150 | 4.7u | GRM21BR71C475KA73L | Capacitor_SMD__C_0805_2012Metric | False
D140 | PESD5V0F1BL | PESD5V0F1BL,315 | GNSS_SOD882 | False | Nexperia low-capacitance unidirectional ESD; cathode pin1 to RF/bias.
U141 | TPS2553 | TPS2553DBVR | GNSS_SOT23_6 | False | TI DBV pin table: 1 IN, 2 GND, 3 EN, 4 FAULT NC, 5 ILIM tied IN, 6 OUT. 50..100 mA limit.
C151 | 10n | GRM188R71H103KA01D | SUP_C_0603_1608Metric | False | Local RF bypass at L140 cold end; short ground stitch.
C152 | 100n | GRM188R71H104KA93D | Capacitor_SMD__C_0603_1608Metric | False | U141 input bypass.

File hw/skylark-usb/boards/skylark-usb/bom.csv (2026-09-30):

Reference | Value | MPN | Footprint | DNP | Note
J1 | TYPE-C-31-M-12 | TYPE-C-31-M-12 | USB_C_HRO_TYPE-C-31-M-12.kicad_mod | False
R1 | 5100R | RC0603FR-075K1L | Resistor_SMD__R_0603_1608Metric.kicad_mod | False
R2 | 5100R | RC0603FR-075K1L | Resistor_SMD__R_0603_1608Metric.kicad_mod | False
D1 | USBLC6-2SC6 | USBLC6-2SC6 | Package_TO_SOT_SMD__SOT-23-6.kicad_mod | False
D2 | USBLC6-2SC6 | USBLC6-2SC6 | Package_TO_SOT_SMD__SOT-23-6.kicad_mod | False
F1 | 500mA PTC | 1206L050YR | Fuse_1206.kicad_mod | False
U2 | AP2112K-3.3TRG1 | AP2112K-3.3TRG1 | Package_TO_SOT_SMD__SOT-23-5.kicad_mod | False
C1 | 1uF | GRM188R71E105KA12D | Capacitor_SMD__C_0603_1608Metric.kicad_mod | False
C2 | 4.7uF | GRM21BR71A475KA73L | Capacitor_SMD__C_0805_2012Metric.kicad_mod | False
U3 | TPS2553DBVR | TPS2553DBVR | Package_TO_SOT_SMD__SOT-23-6.kicad_mod | False
R3 | 82000R | RC0603FR-0782KL | Resistor_SMD__R_0603_1608Metric.kicad_mod | False
R4 | 100000R | RT0603BRD07100KL | Resistor_SMD__R_0603_1608Metric.kicad_mod | False
R5 | 10000R | RT0603BRD0710KL | Resistor_SMD__R_0603_1608Metric.kicad_mod | False
C3 | 100nF | GRM188R71H104KA93D | Capacitor_SMD__C_0603_1608Metric.kicad_mod | False
C4 | 10uF | GRM21BR61A106KE19L | Capacitor_SMD__C_0805_2012Metric.kicad_mod | False
J2 | BM08B-GHS-TBT | BM08B-GHS-TBT | Connector_JST__JST_GH_BM08B-GHS-TBT_1x08-1MP_P1.25mm_Vertical.kicad_mod | False | Numbered 1:1 PMS5003 cable; verify both mating ends. PMS module separately enclosure-mounted.
Q5 | 2N7002/HAMR | 2N7002/HAMR | Package_TO_SOT_SMD__SOT-23.kicad_mod | False
Q6 | 2N7002/HAMR | 2N7002/HAMR | Package_TO_SOT_SMD__SOT-23.kicad_mod | False
R6 | 100000R | RT0603BRD07100KL | Resistor_SMD__R_0603_1608Metric.kicad_mod | False
R7 | 100000R | RT0603BRD07100KL | Resistor_SMD__R_0603_1608Metric.kicad_mod | False
R8 | 4700R | RC0603FR-074K7L | Resistor_SMD__R_0603_1608Metric.kicad_mod | False
R9 | 4700R | RC0603FR-074K7L | Resistor_SMD__R_0603_1608Metric.kicad_mod | False
R10 | 100000R | RT0603BRD07100KL | Resistor_SMD__R_0603_1608Metric.kicad_mod | False
R11 | 100000R | RT0603BRD07100KL | Resistor_SMD__R_0603_1608Metric.kicad_mod | False
C5 | 100nF | GRM188R71H104KA93D | Capacitor_SMD__C_0603_1608Metric.kicad_mod | False
U1 | STM32F072CBT6 | STM32F072CBT6 | Package_QFP__LQFP-48_7x7mm_P0.5mm.kicad_mod | False
C6 | 100nF | GRM188R71H104KA93D | Capacitor_SMD__C_0603_1608Metric.kicad_mod | False
C7 | 100nF | GRM188R71H104KA93D | Capacitor_SMD__C_0603_1608Metric.kicad_mod | False
C8 | 100nF | GRM188R71H104KA93D | Capacitor_SMD__C_0603_1608Metric.kicad_mod | False
C9 | 100nF | GRM188R71H104KA93D | Capacitor_SMD__C_0603_1608Metric.kicad_mod | False
C10 | 1uF | GRM188R71E105KA12D | Capacitor_SMD__C_0603_1608Metric.kicad_mod | False
R12 | 10000R | RT0603BRD0710KL | Resistor_SMD__R_0603_1608Metric.kicad_mod | False
C11 | 100nF | GRM188R71H104KA93D | Capacitor_SMD__C_0603_1608Metric.kicad_mod | False
R13 | 10000R | RT0603BRD0710KL | Resistor_SMD__R_0603_1608Metric.kicad_mod | False
SW1 | TL3342F160QG | TL3342F160QG | Button_Switch_SMD__SW_SPST_TL3342.kicad_mod | False
SW2 | TL3342F160QG | TL3342F160QG | Button_Switch_SMD__SW_SPST_TL3342.kicad_mod | False
J3 | 20021111-00010T4LF | 20021111-00010T4LF | Connector_PinHeader_1.27mm__PinHeader_2x05_P1.27mm_Vertical.kicad_mod | False
R14 | 1000R | RC0603FR-071KL | Resistor_SMD__R_0603_1608Metric.kicad_mod | False
D3 | LTST-C191KGKT | LTST-C191KGKT | LED_SMD__LED_0603_1608Metric.kicad_mod | False
R15 | 10000R | RT0603BRD0710KL | Resistor_SMD__R_0603_1608Metric.kicad_mod | False
R16 | 10000R | RT0603BRD0710KL | Resistor_SMD__R_0603_1608Metric.kicad_mod | False
R17 | 4700R | RC0603FR-074K7L | Resistor_SMD__R_0603_1608Metric.kicad_mod | False
R18 | 4700R | RC0603FR-074K7L | Resistor_SMD__R_0603_1608Metric.kicad_mod | False
R19 | 22R | RC0603FR-0722RL | Resistor_SMD__R_0603_1608Metric.kicad_mod | False
C12 | 10uF | GRM21BR61A106KE19L | Capacitor_SMD__C_0805_2012Metric.kicad_mod | False
U4 | REF3025AIDBZR | REF3025AIDBZR | Package_TO_SOT_SMD__SOT-23.kicad_mod | False
C13 | 1uF | GRM188R71E105KA12D | Capacitor_SMD__C_0603_1608Metric.kicad_mod | False
C14 | 100nF | GRM188R71H104KA93D | Capacitor_SMD__C_0603_1608Metric.kicad_mod | False
R20 | 10000R | RT0603BRD0710KL | Resistor_SMD__R_0603_1608Metric.kicad_mod | False
R21 | 10000R | RT0603BRD0710KL | Resistor_SMD__R_0603_1608Metric.kicad_mod | False
C15 | 1uF | GRM188R71E105KA12D | Capacitor_SMD__C_0603_1608Metric.kicad_mod | False
U5 | OPA387DBVR | OPA387DBVR | Package_TO_SOT_SMD__SOT-23-5.kicad_mod | False
C16 | 100nF | GRM188R71H104KA93D | Capacitor_SMD__C_0603_1608Metric.kicad_mod | False
U6 | ADS122C04IPWR | ADS122C04IPWR | Package_SO__TSSOP-16_4.4x5mm_P0.65mm.kicad_mod | False
C17 | 100nF | GRM188R71H104KA93D | Capacitor_SMD__C_0603_1608Metric.kicad_mod | False
C18 | 100nF | GRM188R71H104KA93D | Capacitor_SMD__C_0603_1608Metric.kicad_mod | False
C19 | 1uF | GRM188R71E105KA12D | Capacitor_SMD__C_0603_1608Metric.kicad_mod | False
GS1 | SGX-7SO2-AQ-20 | SGX-7SO2-AQ-20 | SGX7_AQ_Socket.kicad_mod | False | Four 0322-0-15-15-34-27-10-0 sockets; top footprint mirrors manufacturer bottom view; no direct cell soldering.
U7 | OPA2387DGKR | OPA2387DGKR | Package_SO__VSSOP-8_3x3mm_P0.65mm.kicad_mod | False
U8 | OPA387DBVR | OPA387DBVR | Package_TO_SOT_SMD__SOT-23-5.kicad_mod | False
R30 | 20R | RT0603BRD0720RL | Resistor_SMD__R_0603_1608Metric.kicad_mod | False
R31 | 100000R | RT0603BRD07100KL | Resistor_SMD__R_0603_1608Metric.kicad_mod | False
C30 | 100nF | C3216C0G1H104JT000N | Capacitor_SMD__C_1206_3216Metric.kicad_mod | False | C0G feedback/compensation; H2S feedback totals 500 nF in parallel
R32 | 10000R | RT0603BRD0710KL | Resistor_SMD__R_0603_1608Metric.kicad_mod | False
C31 | 10uF | GRM21BR61A106KE19L | Capacitor_SMD__C_0805_2012Metric.kicad_mod | False
Q1 | MMBFJ270 | MMBFJ270 | Package_TO_SOT_SMD__SOT-23.kicad_mod | False
R33 | 20R | RT0603BRD0720RL | Resistor_SMD__R_0603_1608Metric.kicad_mod | False
R34 | 100000R | RT0603BRD07100KL | Resistor_SMD__R_0603_1608Metric.kicad_mod | False
C33 | 100nF | C3216C0G1H104JT000N | Capacitor_SMD__C_1206_3216Metric.kicad_mod | False | C0G feedback/compensation; H2S feedback totals 500 nF in parallel
R35 | 10000R | RT0603BRD0710KL | Resistor_SMD__R_0603_1608Metric.kicad_mod | False
C34 | 10uF | GRM21BR61A106KE19L | Capacitor_SMD__C_0805_2012Metric.kicad_mod | False
Q2 | MMBFJ270 | MMBFJ270 | Package_TO_SOT_SMD__SOT-23.kicad_mod | False
R36 | 10000R | RT0603BRD0710KL | Resistor_SMD__R_0603_1608Metric.kicad_mod | False
R37 | 100R | RC0603FR-07100RL | Resistor_SMD__R_0603_1608Metric.kicad_mod | False
C36 | 100nF | C3216C0G1H104JT000N | Capacitor_SMD__C_1206_3216Metric.kicad_mod | False | C0G feedback/compensation; H2S feedback totals 500 nF in parallel
C37 | 100nF | GRM188R71H104KA93D | Capacitor_SMD__C_0603_1608Metric.kicad_mod | False
C38 | 100nF | GRM188R71H104KA93D | Capacitor_SMD__C_0603_1608Metric.kicad_mod | False
GS2 | SGX-7H2S-AQ-25 | SGX-7H2S-AQ-25 | SGX7_AQ_Socket.kicad_mod | False | Four 0322-0-15-15-34-27-10-0 sockets; top footprint mirrors manufacturer bottom view; no direct cell soldering.
U9 | OPA2387DGKR | OPA2387DGKR | Package_SO__VSSOP-8_3x3mm_P0.65mm.kicad_mod | False
U10 | OPA387DBVR | OPA387DBVR | Package_TO_SOT_SMD__SOT-23-5.kicad_mod | False
R50 | 20R | RT0603BRD0720RL | Resistor_SMD__R_0603_1608Metric.kicad_mod | False
R51 | 20000R | RT0603BRD0720KL | Resistor_SMD__R_0603_1608Metric.kicad_mod | False
C50 | 100nF | C3216C0G1H104JT000N | Capacitor_SMD__C_1206_3216Metric.kicad_mod | False | C0G feedback/compensation; H2S feedback totals 500 nF in parallel
R52 | 10000R | RT0603BRD0710KL | Resistor_SMD__R_0603_1608Metric.kicad_mod | False
C51 | 10uF | GRM21BR61A106KE19L | Capacitor_SMD__C_0805_2012Metric.kicad_mod | False
Q3 | MMBFJ270 | MMBFJ270 | Package_TO_SOT_SMD__SOT-23.kicad_mod | False
R53 | 20R | RT0603BRD0720RL | Resistor_SMD__R_0603_1608Metric.kicad_mod | False
R54 | 20000R | RT0603BRD0720KL | Resistor_SMD__R_0603_1608Metric.kicad_mod | False
C53 | 100nF | C3216C0G1H104JT000N | Capacitor_SMD__C_1206_3216Metric.kicad_mod | False | C0G feedback/compensation; H2S feedback totals 500 nF in parallel
R55 | 10000R | RT0603BRD0710KL | Resistor_SMD__R_0603_1608Metric.kicad_mod | False
C54 | 10uF | GRM21BR61A106KE19L | Capacitor_SMD__C_0805_2012Metric.kicad_mod | False
Q4 | MMBFJ270 | MMBFJ270 | Package_TO_SOT_SMD__SOT-23.kicad_mod | False
R56 | 10000R | RT0603BRD0710KL | Resistor_SMD__R_0603_1608Metric.kicad_mod | False
R57 | 100R | RC0603FR-07100RL | Resistor_SMD__R_0603_1608Metric.kicad_mod | False
C56 | 100nF | C3216C0G1H104JT000N | Capacitor_SMD__C_1206_3216Metric.kicad_mod | False | C0G feedback/compensation; H2S feedback totals 500 nF in parallel
C57 | 100nF | GRM188R71H104KA93D | Capacitor_SMD__C_0603_1608Metric.kicad_mod | False
C58 | 100nF | GRM188R71H104KA93D | Capacitor_SMD__C_0603_1608Metric.kicad_mod | False
R70 | 10000R | RT0603BRD0710KL | Resistor_SMD__R_0603_1608Metric.kicad_mod | False
R71 | 100000R | RT0603BRD07100KL | Resistor_SMD__R_0603_1608Metric.kicad_mod | False | Gate return to electrode common mode, not ground
U11 | SHT40-AD1F-R2 | SHT40-AD1F-R2 | SHT40.kicad_mod | False
C70 | 100nF | GRM188R71H104KA93D | Capacitor_SMD__C_0603_1608Metric.kicad_mod | False
U12 | BMP388 | BMP388 | BMP388.kicad_mod | False
C71 | 100nF | GRM188R71H104KA93D | Capacitor_SMD__C_0603_1608Metric.kicad_mod | False
C72 | 100nF | GRM188R71H104KA93D | Capacitor_SMD__C_0603_1608Metric.kicad_mod | False
TP1 | Test pad 1mm | Test pad 1mm | TestPoint__TestPoint_Pad_D1.0mm.kicad_mod | False
TP2 | Test pad 1mm | Test pad 1mm | TestPoint__TestPoint_Pad_D1.0mm.kicad_mod | False
TP3 | Test pad 1mm | Test pad 1mm | TestPoint__TestPoint_Pad_D1.0mm.kicad_mod | False
TP4 | Test pad 1mm | Test pad 1mm | TestPoint__TestPoint_Pad_D1.0mm.kicad_mod | False
TP5 | Test pad 1mm | Test pad 1mm | TestPoint__TestPoint_Pad_D1.0mm.kicad_mod | False
TP6 | Test pad 1mm | Test pad 1mm | TestPoint__TestPoint_Pad_D1.0mm.kicad_mod | False
TP7 | Test pad 1mm | Test pad 1mm | TestPoint__TestPoint_Pad_D1.0mm.kicad_mod | False
U13 | TPS22918DBVR | TPS22918DBVR | Package_TO_SOT_SMD__SOT-23-6.kicad_mod | False | Analog power sequencing / USB suspend
Q7 | MMBT3904LT1G | MMBT3904LT1G | Package_TO_SOT_SMD__SOT-23.kicad_mod | False | Emitter follows VZERO; base resistor R74 limits MCU current
R72 | 100000R | RT0603BRD07100KL | Resistor_SMD__R_0603_1608Metric.kicad_mod | False | Analog power sequencing / USB suspend
R73 | 10000R | RT0603BRD0710KL | Resistor_SMD__R_0603_1608Metric.kicad_mod | False | Analog power sequencing / USB suspend
C73 | 1uF | GRM188R71E105KA12D | Capacitor_SMD__C_0603_1608Metric.kicad_mod | False | Analog power sequencing / USB suspend
C74 | 10nF | GRM188R71H103KA01D | Capacitor_SMD__C_0603_1608Metric.kicad_mod | False | Analog power sequencing / USB suspend
H1 | M3 | Mechanical | MountingHole__MountingHole_3.2mm_M3.kicad_mod | False | M3 support
H2 | M3 | Mechanical | MountingHole__MountingHole_3.2mm_M3.kicad_mod | False | M3 support
H3 | M3 | Mechanical | MountingHole__MountingHole_3.2mm_M3.kicad_mod | False | M3 support
H4 | M3 | Mechanical | MountingHole__MountingHole_3.2mm_M3.kicad_mod | False | M3 support
R74 | 10000R | RT0603BRD0710KL | Resistor_SMD__R_0603_1608Metric.kicad_mod | False | Q7 base current limit
D4 | BAT54LT1G | BAT54LT1G | Package_TO_SOT_SMD__SOT-23.kicad_mod | False | 1 anode USB_5V; 3 cathode GATE_SUPPLY; 2 NC
C80 | 100nF | C3216C0G1H104JT000N | Capacitor_SMD__C_1206_3216Metric.kicad_mod | False | H2S C0G parallel feedback bank
C81 | 100nF | C3216C0G1H104JT000N | Capacitor_SMD__C_1206_3216Metric.kicad_mod | False | H2S C0G parallel feedback bank
C82 | 100nF | C3216C0G1H104JT000N | Capacitor_SMD__C_1206_3216Metric.kicad_mod | False | H2S C0G parallel feedback bank
C83 | 100nF | C3216C0G1H104JT000N | Capacitor_SMD__C_1206_3216Metric.kicad_mod | False | H2S C0G parallel feedback bank
C84 | 100nF | C3216C0G1H104JT000N | Capacitor_SMD__C_1206_3216Metric.kicad_mod | False | H2S C0G parallel feedback bank
C85 | 100nF | C3216C0G1H104JT000N | Capacitor_SMD__C_1206_3216Metric.kicad_mod | False | H2S C0G parallel feedback bank
C86 | 100nF | C3216C0G1H104JT000N | Capacitor_SMD__C_1206_3216Metric.kicad_mod | False | H2S C0G parallel feedback bank
C87 | 100nF | C3216C0G1H104JT000N | Capacitor_SMD__C_1206_3216Metric.kicad_mod | False | H2S C0G parallel feedback bank
R75 | 100R | RC0603FR-07100RL | Resistor_SMD__R_0603_1608Metric.kicad_mod | False | 100 ohm isolation for driven electrode guard pours
GS1/GS2 sockets (8) | 1 mm cell sockets | 0322-0-15-15-34-27-10-0 | SGX7_AQ_Socket | False | Install sockets before inserting cells
External PM module | PMS5003 | PMS5003 | Enclosure cradle | False | Separate cable, not soldered on this PCB

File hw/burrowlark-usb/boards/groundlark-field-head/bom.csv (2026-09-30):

Reference | Value | MPN | Footprint | DNP | Note
J1 | USB-C DEVICE | USB4105-GF-A | Connector_USB__USB_C_Receptacle_GCT_USB4105-xx-A_16P_TopMnt_Horizontal | False
R1 | 5.1k | RC0603FR-075K1L | Resistor_SMD__R_0603_1608Metric | False
R2 | 5.1k | RC0603FR-075K1L | Resistor_SMD__R_0603_1608Metric | False
D1 | USBLC6-2SC6 | USBLC6-2SC6 | Package_TO_SOT_SMD__SOT-23-6 | False
D2 | USBLC6-2SC6 | USBLC6-2SC6 | Package_TO_SOT_SMD__SOT-23-6 | False
F1 | 500mA PTC | MF-MSMF050-2 | Fuse__Fuse_1812_4532Metric | False
U4 | AP2112K-3.3 | AP2112K-3.3TRG1 | Package_TO_SOT_SMD__SOT-23-5 | False
C1 | 2.2u | GRM21BR71E225KA73L | Capacitor_SMD__C_0805_2012Metric | False
C2 | 4.7u | GRM21BR71A475KA73L | Capacitor_SMD__C_0805_2012Metric | False
U1 | STM32F042K6T6 | STM32F042K6T6 | Package_QFP__LQFP-32_7x7mm_P0.8mm | False
C3 | 100n | GRM188R71H104KA93D | Capacitor_SMD__C_0603_1608Metric | False
C6 | 100n | GRM188R71H104KA93D | Capacitor_SMD__C_0603_1608Metric | False
C7 | 100n | GRM188R71H104KA93D | Capacitor_SMD__C_0603_1608Metric | False
C8 | 100n | GRM188R71H104KA93D | Capacitor_SMD__C_0603_1608Metric | False
R3 | 10k | RC0603FR-0710KL | Resistor_SMD__R_0603_1608Metric | False
R4 | 10k | RC0603FR-0710KL | Resistor_SMD__R_0603_1608Metric | False
J2 | SWD / 3V3 SENSE | M20-9990545 | Connector_PinHeader_2.54mm__PinHeader_1x05_P2.54mm_Vertical | False | Pin 1 is target voltage sense; do not externally power the rail
J3 | BOOT0 jumper | EEPROM write enable | Connector_PinHeader_2.54mm__PinHeader_1x02_P2.54mm_Vertical | False
U5 | TPS22919 | TPS22919DCKR | Package_TO_SOT_SMD__SOT-363_SC-70-6 | False
R5 | 100k | RC0603FR-07100KL | Resistor_SMD__R_0603_1608Metric | False
C9 | 100n | GRM188R71H104KA93D | Capacitor_SMD__C_0603_1608Metric | False
R7 | 4.7k | RC0603FR-074K7L | Resistor_SMD__R_0603_1608Metric | False
R8 | 4.7k | RC0603FR-074K7L | Resistor_SMD__R_0603_1608Metric | False
U2 | RM3100 XYZ | PNI 14190 | Groundlark__PNI_14190_Module | False
C4 | 100n | GRM188R71H104KA93D | Capacitor_SMD__C_0603_1608Metric | False
H1 | M2.5 NPTH | M2.5 NPTH | MountingHole__MountingHole_2.7mm_M2.5 | False
H2 | M2.5 NPTH | M2.5 NPTH | MountingHole__MountingHole_2.7mm_M2.5 | False
H3 | M2.5 NPTH | M2.5 NPTH | MountingHole__MountingHole_2.7mm_M2.5 | False
H4 | M2.5 NPTH | M2.5 NPTH | MountingHole__MountingHole_2.7mm_M2.5 | False
U6 | SHT45 | SHT45-AD1B-R2 | SHT45 | False | Enclosure temperature/humidity; 0x44; heater disabled; keep sensing opening exposed
C10 | 100n | GRM188R71H104KA93D | Capacitor_SMD__C_0603_1608Metric | False | SHT45 local bypass

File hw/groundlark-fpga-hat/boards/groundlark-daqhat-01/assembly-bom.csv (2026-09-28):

Item | Quantity | Part | Note
Carrier assembly | 1 | Groundlark DAQHAT-01 | Use generated bom.csv for carrier electronic components
FPGA module | 1 | TE0712-03-81I36-A | XC7A200T-1FBG484I; standard 4 mm connectors
Trenz spacers | 4 | M3 8 mm surface-gap spacers | Match actual mating stack; insulated hardware preferred near copper
Trenz fasteners | 4 | M3 screws | Select length for actual spacers; avoid bottoming
Pi GPIO riser | 2 | Samtec SSQ-120-02-G-D | Unmounted 2x20 socket; 8.51 mm body; 4.93 mm square gold-flash tails into J1; female face toward Pi; verify full insertion and 1:1 pin numbering
Pi spacers | 4 | Approximately 28.06 mm effective clearance | Select measured spacers/shims for Megastar ZX-PM2.54-2-20PY plus two SSQ risers and Pi header mating
Pi fasteners | 4 | M2.5 screws | Select length for actual spacers
Host | 1 | Raspberry Pi 4 Model B | Selected bench host; Pi 5 not covered by this fit review
Module power | 1 | Adjustable regulated current-limited supply | 3.35 V +/-0.5% at J83; maintain 3.201-3.399 V at module; total hot supply-and-ground path <=30 milliohms for 3 A operating budget
Cooling | 1 | Workload-dependent FPGA heatsink | Select after power/thermal testing; not included in nominal height model
Geophone cable plug | 1 | Phoenix Contact 1803581 | MC 1.5/3-ST-3.81; mates horizontal 1803280 J90; reserve 12 mm outward withdrawal; release cable clamp before unplugging; see docs/stack-assembly.md
External geophone | 1 | Racotech RGI-4.5Hz vertical | 395 ohm; 23.4 V/(m/s); separate vertical ground-coupled mount
Pi heatsink | 1 | 18 x 18 x 10 mm heatsink from Raspberry Pi 4 Case Fan kit | Heatsink only; 0.5 mm adhesive envelope; fan absent; thermal performance pending

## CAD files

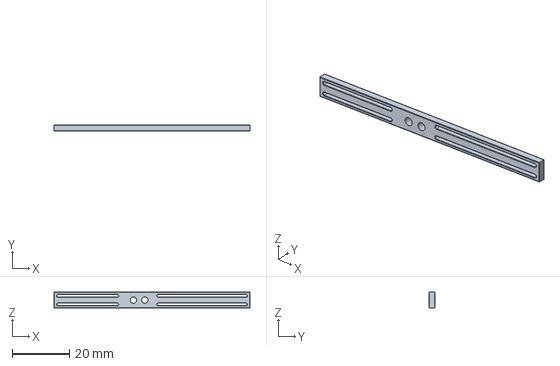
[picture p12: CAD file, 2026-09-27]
hw/groundlark-fpga-hat/mechanical/daqhat-01-ribbon-guide/ribbon-guide.step
68.5 x 2.00 x 5.50 mm

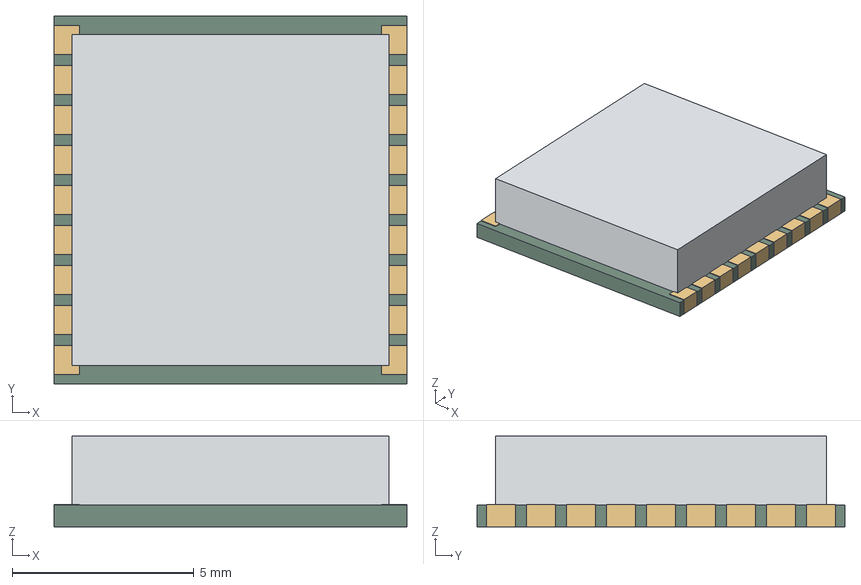
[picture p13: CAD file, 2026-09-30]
hw/shared/models/MAX_M10S_envelope.step
9.70 x 10.1 x 2.50 mm
substrate
shield
contact_-1_0
contact_-1_1
contact_-1_2
contact_-1_3
contact_-1_4
contact_-1_5
contact_-1_6
contact_-1_7
contact_-1_8
contact_1_0
contact_1_1
contact_1_2
contact_1_3
contact_1_4
contact_1_5
contact_1_6
contact_1_7
contact_1_8

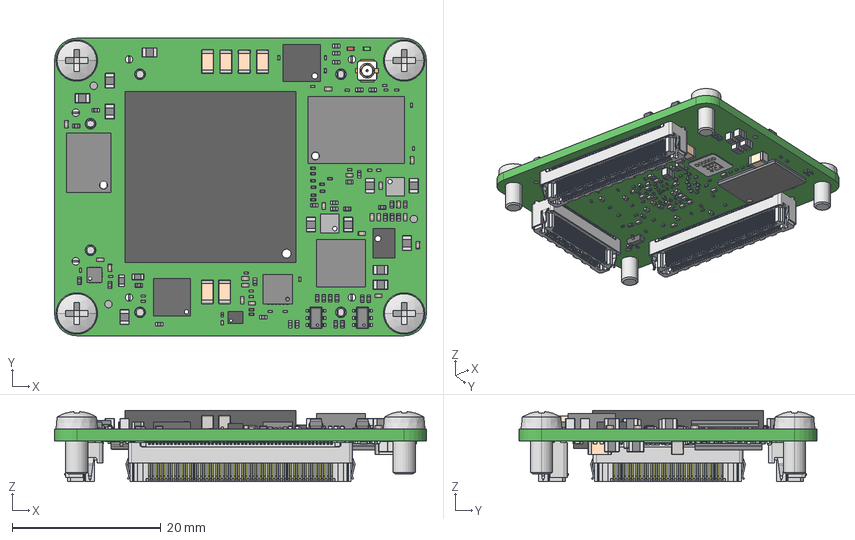
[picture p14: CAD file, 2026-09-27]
hw/shared/models/trenz/STP-TE0712-03-No Variations.step
50.0 x 40.0 x 9.61 mm
RES_0603-0201 x 28
User Library-SMD CAPACITOR0402 x 51
User Library-SMD 0201 CAPACITOR x 92
Extruded x 8
User Library-CAPC3216X___CAPC3216X180N x 9
ASMPH-0603 x 2
User Library-QFN24-0_5_Fusion
User Library-QFN24-0_5_QFN24_0_5024
User Library-QFN24-0_5_Cut
_STRLSHM-30-04.0-DV-A-S
_C-185--30-04.0-DV1P
_STRLSHM-50-04.0-DV-A-S x 2
_C-185--50-04.0-DV1P x 2
622173x6 x 4
led_0402LED0402 green
led_0402-red
SW3dPS-U.FL-R-SMT-1
Label

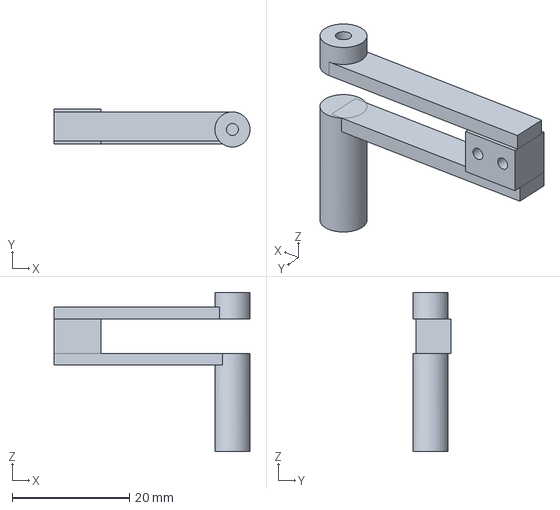
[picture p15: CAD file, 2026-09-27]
hw/groundlark-fpga-hat/mechanical/daqhat-01-ribbon-guide/offset-spacer.step
33.5 x 6.50 x 27.2 mm

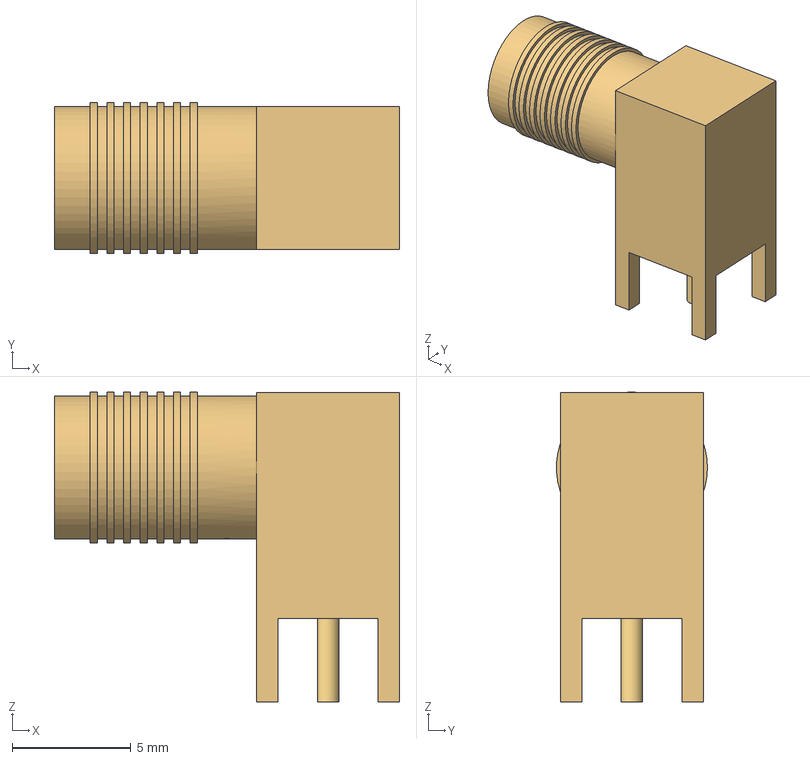
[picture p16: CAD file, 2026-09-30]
hw/shared/models/HL_SMA_KWE_02.step
14.5 x 6.34 x 13.0 mm
gold_body
PTFE
socket_and_pin

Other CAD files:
hw/shared/models/DAQHAT_01_offset-spacer.step
hw/shared/models/DAQHAT_01_ribbon-guide.step
hw/groundlark-fpga-hat/mechanical/daqhat-01-ribbon-guide/offset-spacer.stl
hw/groundlark-fpga-hat/mechanical/daqhat-01-ribbon-guide/ribbon-guide.stl

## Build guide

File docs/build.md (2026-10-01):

# Reproducible hardware builds

For validation in an isolated, portable environment, use the
[portable lab](portable-lab.md). It does not depend on the migrated local venvs.

The Pi-outline DAQHAT-01 build and rendering commands are in
[Trenz carrier documentation](trenz-hat.md#rebuild).

Used environment: WSL Ubuntu 24.04, atopile 0.15.9 with Python 3.14.7,
KiCad/pcbnew 9.0.9, ngspice 42 and Freerouting 1.9.0. These lower-level commands
require KiCad's system Python bindings, sexpdata, and ngspice in Linux/WSL.
Recreate an optional local atopile environment with an installed `uv`:

```sh
uv venv --python 3.14.7 .local/atopile
uv pip sync --python .local/atopile/bin/python --require-hashes environment/requirements.lock
```

Run the following from the repository root. They write authoring outputs; use
the portable lab for disposable validation instead. Freerouting's jar is a local
dependency at `hw/tools/freerouting-1.9.0.jar`, excluded from Git.

```sh
mkdir -p hw/logs
CI=1 .local/atopile/bin/python -m atopile build -v hw > hw/logs/atopile-build.log 2>&1
.local/atopile/bin/python hw/tools/solve_constraints.py > hw/logs/constraint-solve.log 2>&1
.local/atopile/bin/python hw/tools/solve_constraints.py --negative > hw/logs/negative-voltage.log 2>&1
python3 hw/tools/simulate.py
python3 hw/tools/assemble_pcb.py
```

`solve_constraints.py` explicitly invokes atopile's full numeric solver for
voltage/resistance/capacitance parameters. This is necessary because the stock
0.15.9 picker skips numeric solving for manually selected atomic components.
The negative case must reject 5 V applied to the 3.6 V IMU. No installed package
is patched and no electrical check is disabled. Component ratings use `assert
... within`; power sources specify their delivered range.

`assemble_pcb.py` resets routing, applies mechanical placement, adds the outline
and plane rules, and exports Specctra. It reads the compiled native KiCad board;
it does not create connections from a Python netlist. Save manual layout changes
before rerunning it. Electrical source is in each product's `elec/` directory,
with common definitions in `hw/shared/elec/`. Each product's
`layout/placement.json` has no pin net assignments. Review BOM presentation
metadata when changing a selected MPN.

The commands below rebuild Burrowlark. DAQHAT-01 and Skylark have dedicated
authoring and validation commands in their product guides.
The checked route sessions are supplied with the boards. Reconstruct the
delivered layout after `assemble_pcb.py` with:

```sh
python3 hw/tools/import_routes.py
python3 hw/tools/trim_dangling.py
python3 hw/tools/widen_power.py
python3 hw/tools/review_schematic.py
python3 hw/tools/models.py
python3 hw/tools/check_circuit.py
python3 hw/tools/check_design.py
```

The power-width pass tries 0.4/0.3/0.25/0.2 mm and uses native DRC to retain only
legal widening. Remaining 0.15 mm sections and per-net lengths are recorded in
`power-widths.json`; this is not an ampacity or extracted voltage-drop analysis.

For a changed placement/circuit, reroute each board and repeat the checks:

```sh
xvfb-run -a java -jar hw/tools/freerouting-1.9.0.jar \
  -de hw/burrowlark-usb/boards/groundlark-field-head/groundlark-field-head.dsn \
  -do hw/burrowlark-usb/boards/groundlark-field-head/groundlark-field-head.ses -mp 25 -mt 1 -da
python3 hw/tools/import_routes.py
python3 hw/tools/trim_dangling.py
python3 hw/tools/widen_power.py
python3 hw/tools/review_schematic.py
python3 hw/tools/models.py
python3 hw/tools/check_design.py
```

The restricted SES importer verifies placements and rejects unsupported route
objects. KiCad performs independent DRC afterwards. Review schematics use local
symbols with physical pin numbers, explicit no-connects and documented supply
flags. They are derived artifacts, not a second electrical source.

Autorouter completion is never assumed from a successful process exit; the
independent unconnected-net check is required. Use each product's documented
render command to refresh its actual native PCB view.

The KiCad project opens directly in PCB Editor; use Alt+3 for its interactive 3D
viewer. Stock models require KiCad's 3D packages. Custom envelopes are portable
under `hw/shared/models/`. Prototype render geometry is not mechanical signoff.

Do not use the empty BOM emitted by atopile's automatic picker: this design uses
manual manufacturer parts. The explicit per-board `bom.csv` files are the review
BOMs. No purchase, assembly order or board fabrication was submitted.

Render the current RM3100/SHT45 Burrowlark PCB with
`python3 hw/tools/render_burrowlark.py`. It verifies that U3/C5 are absent and
records PCB, model and image hashes in `render-provenance.json`. Refresh its
schematic, assembly and layout previews with
`python3 hw/tools/export_previews.py groundlark-field-head`. These commands
read the native CAD without rerouting or rewriting it; KiCad models, Xvfb for
headless rendering, and `rsvg-convert` for preview PNGs must be installed.

For a Burrowlark-only CAD check, run
`python3 hw/tools/check_circuit.py --board groundlark-field-head` and
`python3 hw/tools/check_design.py --board groundlark-field-head`. The latter
refreshes its ERC, DRC, netlist and validation reports without changing the PCB.
The full portable lab remains the required cross-product regression check.

Burrowlark identity artwork is authored in the `silkscreen` section of
`hw/burrowlark-usb/layout/placement.json` and applied during board assembly.
To refresh only these board graphics on existing routed CAD, run
`python hw/tools/burrowlark_silkscreen.py` in the KiCad Python environment, then
run the native design check and regenerate the render/previews. The command
verifies that copper is unchanged; it uses the shared 7 mm favicon artwork.

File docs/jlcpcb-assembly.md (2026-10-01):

# JLCPCB assembled DAQHAT-01 HAT

The package targets **one fabricated PCB and one assembled HAT**, the same
physical board. The current HAT is 140 × 56 mm. The frozen procurement/placement
registry still describes the earlier 117-placement, 38-line assembly.

**Export hold:** U23/C24, the 12 V FPGA input and the TI Pi supervisor require procurement
and numbered supplier-pad review. J83/F80 changed part identity; U80, SW80,
D80/D81, R120–R124, C86–C89 and C110–C112 are new. No current stock or supplier
rotation is claimed for these selections. Dated live stock observations for the
corrected fuse, supervisor, divider and antenna parts are recorded in
[power-gnss-selection.json](../hw/assembly/groundlark-fpga-hat/power-gnss-selection.json).
The exact DLVR-F50D-E1BS-I-NI3F still has no confirmed JLCPCB match. Full assembly regression remains
blocked by this mismatch; native circuit, DRC/ERC and routing replay are checked
separately. The 40 Pi supply/supervisor additions are listed in
`hw/assembly/groundlark-fpga-hat/pi-supervisor-review.json` with catalog and
supplier-pad evidence pending. Earlier packages do not describe the enlarged board.
The Pi, Trenz module, geophone, riser, supply and mounting hardware are separate
purchases. The USB sensor heads are not included.

## Files to upload

| File | Purpose |
| --- | --- |
| `DAQHAT-01-Gerbers-REVIEW.zip` | Current full-export fabrication data. |
| `BOM-review.csv` and `CPL-review.csv` together | Matching current full-export part selections and placements. |

Generate a complete package with the commands below before ordering. The older
2026-09-26 local packages predate the current copper and part selections; do not
combine their Gerbers with the revised BOM.

Use the BOM and CPL from the same fresh full export, or the same corrected
overlay. Do not mix versions or reuse previous manual rotation overrides. Gerbers contain one closed outline;
BOM quantities are per HAT. Set the supplier's PCB and assembly quantities
separately: the CSV cannot control the website's quantity selector.

Packages remain local and Git-ignored. They include checksums and validation
records; source CAD, part, side or process changes require a fresh export.
The package retains manufacturing holds and is not a fabrication approval.

## Fabrication and assembly requirements

- Six-layer FR-4, nominal 1.6 mm, TG135, ENIG, 1 oz outer / 0.5 oz inner copper.
  Use the stock JLC06161H-3313 stack, with no HDI or custom lamination.
  Its 1.5384 mm copper/dielectric sum is ordered as nominal 1.6 mm, ±10%.
- Through-vias only, 0.30/0.40 mm drills, epoxy-filled and copper-capped (POFV),
  including vias in solder pads. Tenting alone is insufficient.
  Do not fill component plated holes or non-plated mounting holes.
- Double-sided assembly. The earlier frozen registry has 107 SMT-only placements,
  seven THT-only placements and three mixed SMT/THT connectors; these counts must
  be regenerated after the export hold is resolved. J80/J81/J82 have SMT contacts and plated mounts.
  J1 is the bottom Pi socket.
- Confirm the supplier's one-piece assembly acceptance, handling frame,
  fiducials, part allocation and process requirements. Recorded Standard PCBA
  rules require a two-piece minimum and a 70 mm minimum dimension; the 140 × 56 mm
  HAT therefore needs a supplier-agreed quantity exception and handling frame.
  Do not change the requested quantity without the owner's agreement.
- Verify the supplier placement preview and final proposed production data.
  CAD, modeled tests and catalog pad fits do not establish physical fit or DFM approval.

## BOM mapping and selected parts

The [exact-part registry](../hw/assembly/groundlark-fpga-hat/daqhat-01-jlcpcb-parts.json) binds each
reference to its source value/footprint and approved manufacturer, MPN and C-code.
Catalog listing does not reserve stock or guarantee assembly eligibility.
Recheck allocation at ordering; do not accept automatic substitutes.

The earlier registry's 38 unique PCB selections (117 placements) have a dated **2026-09-27**
JLCPCB available-order observation and **minimum quantity 1**. Pre-order-only
parts and component minimums above one are prohibited. The exporter rejects
missing, insufficient or nonconforming recorded stock observations; offline
checks do not establish current stock. Recheck allocation before ordering.

| Reference | Selected replacement | Available order quantity / minimum |
| --- | --- | --- |
| U40 | ST LDL1117S33R / C435835 | 23,204 / 1 |
| D90 | TI TPD2E2U06QDCKRQ1 / C915089 | 6,229 / 1 |

The source circuit identifiers remain bound to explicit assembly overrides.
U40 retains GND/OUT/IN pins 1/2/3 and output tab. Its ceramic output capacitor
must retain at least 4.7 µF effective capacitance; C42 is 22 µF X5R, 25 V.
Allow ±3% regulator accuracy plus load/line regulation within the existing
3.18–3.42 V sensor-rail envelope. ST specifies typical 60 µVrms **per volt of
output** (198 µVrms at 3.3 V), 10 Hz–100 kHz; this is not an input-referred
geophone noise prediction. Retain the ADC analog RC filter.
D90's automotive variant preserves the SC-70 pinout, 5.5 V standoff, 10 nA
maximum leakage at 2.5 V and 1.5 pF typical capacitance.
See [ST LDL1117](https://www.st.com/resource/en/datasheet/ldl1117.pdf) and
[TI TPD2E2U06-Q1](https://www.ti.com/lit/ds/symlink/tpd2e2u06-q1.pdf).

Stock is not reserved. Component MOQ 1 does not remove assembly attrition,
process charges or the separate PCB/assembly service minimum described above.
The Pi, Trenz module, external geophone and risers remain outside this PCB BOM.

| Upload field | CSV column |
| --- | --- |
| Comment / manufacturer part number | `Comment` (full orderable MPN) |
| Designator | `Designator` |
| Footprint / package | `Footprint` |
| JLCPCB / LCSC part number | `JLCPCB Part #` |

Do not use `Description` as the ordering code. Confirm all 38 nonblank catalog
identities and all 117 placements survive import.

| References | Assembly selection | Required specification |
| --- | --- | --- |
| J1 | Megastar ZX-PM2.54-2-20PY / C7499354 | Bottom-mounted 2×20 female socket, 8.5 mm body; use two external SSQ risers and measured supports. |
| C42, C80–C82 | Samsung CL31A226KAHNNNE / C12891 | 22 µF, ±10%, X5R, 25 V, 1206. |
| C84, C85 | Murata GRM21BR71C475KE51L / C408144 | 4.7 µF, ±10%, X7R, 16 V, 0805. |
| C90 | Murata GRM31C5C1H104JA01L / C97946 | 100 nF, ±5%, C0G, 50 V, 1206. |
| C91, C92 | KEMET C0603C102J5GAC7867 / C140950 | 1 nF, ±5%, C0G, 50 V, 0603. |
| F80 | Littelfuse 0466005.NRHF / C57525 | 5 A fast fuse, 32 V, 1206. |

F80 must use the 1206 assembly selection; the 0603 source-schematic MPN is not
an approved assembly part. Its nominal cold resistance is 11 mΩ, which is
included in the **30 mΩ total hot power-loop budget**, not an allowance in
addition to it. Check hot voltage drop, startup and fuse behavior on hardware.
Signal capacitors C90–C92 must retain C0G dielectric, tolerance and voltage rating.

**J1 stack:** the model uses the selected 8.5 mm socket plus two external
SSQ-120-02-G-D risers, giving 28.06 mm nominal Pi-top to HAT-underside clearance.
Four supports must match the measured seated height. The old tall Samtec socket
model and one-riser assembly are superseded. Contact engagement, retention and
GPIO signal integrity still require first-article checks; see [stack assembly](stack-assembly.md).

## Placement conventions

J90 uses Phoenix Contact **1803280 / C480530**, the horizontal 3.81 mm header.
Its exact numbered supplier pads are frozen in the placement registry. The
2026-09-28 live catalog showed 2,209 available to order, MOQ 1; stock is not reserved.
The matching 1803581 cable plug is separately sourced.

The exporter fits supplier numbered pads to native footprints using the frozen
[catalog geometry](../hw/assembly/groundlark-fpga-hat/daqhat-01-jlcpcb-placement.json). It accounts
for bottom-side projection and preserves absolute component positions.
Use its CPL rather than raw KiCad angles or manual per-reference offsets.

| References | Supplier CPL rotation |
| --- | --- |
| J1 (Bottom) | 0° |
| J4 | 270° |
| JP1, JP80, JP81 | 0° |
| J80, J81 | 180° |
| J82, J83 | 270° |
| J90 | 0° |
| U1, U22, U41, U42 | 270° |
| U100–U103 (Bottom) | 270° |
| Q1, U40, U51, U52 | 180° |
| D90 (Bottom, C915089) | 90° |
| C91, C92 (Top) | 0° |

Check J1's underside model and pin-1 direction in the supplier preview. Its
front-layer land pattern requires a bottom-mounted socket. Confirm mixed
SMT/THT assembly, reflow/cleaning limits and sensor handling with the supplier.
Each placement must have a part-bound catalog mapping
or explicit exception. Changed MPNs or footprints invalidate those mappings.
The full exporter and overlay use the same solver; repeated export does not
apply an extra rotation. This checks registration, not solder-joint reliability.

## Reproduce exports without changing CAD

Use KiCad 9.0.9 and a Python that imports `pcbnew` (WSL or the portable lab).
The exporter rejects source CAD/BOM hashes that differ from recorded validation,
checks all native DRC severities, validates the layer/drill inventory, and verifies
that BOM and CPL references agree. It refuses to overwrite a populated directory.

```bash
python3 hw/tools/jlcpcb_package.py --quantity 1 --output .local/jlcpcb/new-review
python3 -m unittest discover -s hw/tests -p 'test_jlcpcb*.py' -v
```

For optional independent plot inspection and PDF production, keep dependencies
inside the repo rather than installing into the atopile environment. The review
renderer uses rsvg-convert for luminance masks so silkscreen cutouts preserve
underlying copper, and draws the silkscreen above copper:

```bash

# Also requires rsvg-convert (librsvg2-bin on Debian/Ubuntu).
python3 -m venv --system-site-packages .local/fab-venv
.local/fab-venv/bin/pip install gerbonara==1.5.0 reportlab==4.4.10
.local/fab-venv/bin/python hw/tools/jlcpcb_inspect.py .local/jlcpcb/new-review
.local/fab-venv/bin/python hw/tools/jlcpcb_drawings.py .local/jlcpcb/new-review
```

The independent parser compares every exported hole location, diameter and
span to CAD (1 micrometre coordinate quantization), and parses all 13 plot layers.
The package report gives actual drill counts; no blind-drill files are accepted.
It emits benign parser warnings about KiCad's G90 header position and unused
RoundRect macro parameters; these are retained rather than suppressed. Render
the PDF with `pdftoppm` and inspect each page. Gerber parsing does not establish
DFM approval or validate solder-paste apertures against supplier process limits.

After adding the package README and reviewing the PDF, run
`python3 hw/tools/jlcpcb_seal.py .local/jlcpcb/new-review` to write checksums
and the complete review ZIP. This retains all manufacturing holds; it does not
promote the package to an approved release.
The assembly PDF reads J1 and J90 manufacturer, MPN and catalog identity from
that package's procurement CSV, keeping its instructions aligned with the BOM.

## Sources reviewed 2026-09-25

- [JLCPCB assembly capabilities](https://jlcpcb.com/capabilities/pcb-assembly-capabilities):
  Standard service, two-piece minimum, panel dimensions, rails and fiducials.
- [PCB capabilities](https://jlcpcb.com/capabilities/Capab) and
  [six-layer POFV](https://jlcpcb.com/news/free-via-in-pad-6-20-layer-pcbs-pofv).
- [KiCad 9 export guide](https://jlcpcb.com/help/article/how-to-generate-gerber-and-drill-files-in-kicad-9).
- [BOM format](https://jlcpcb.com/help/article/bill-of-materials-for-pcb-assembly)
  and [CPL format](https://jlcpcb.com/help/article/pick-place-file-for-pcb-assembly).
- [Parts sourcing](https://jlcpcb.com/help/article/pcba-parts-sourcing-instruction).
- [LSM6DSOTR catalog](https://jlcpcb.com/partdetail/LSM6DSOTR/C2655100)
  and [TCA9534PWR catalog](https://jlcpcb.com/partdetail/TexasInstruments-TCA9534PWR/C783615).

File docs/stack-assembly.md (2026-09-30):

# DAQHAT-01 bench assembly

Bottom to top: Pi 4, 140 x 56 mm DAQHAT-01 sensor HAT, TE0712-03-81I36-A.
Four straight Pi supports replace the previous ribbon guide and offset spacer.
J84-J89 and all external FPGA ribbon cables are removed. Programming and data
travel through J1 and the Trenz mezzanine connectors; see the
[host-link guide](fpga-host-link.md).

## Selected hardware

| Item | Selection | Fit rule |
| --- | --- | --- |
| Host | Raspberry Pi 4 Model B | Pi 5/cooler not covered. |
| Pi cooling | Official Pi 4 Case Fan kit 18 x 18 x 10 mm heatsink | Allow 0.5 mm adhesive; fan omitted. |
| Pi riser | Two SSQ-120-02-G-D risers plus Megastar ZX-PM2.54-2-20PY J1 | 28.06 mm nominal Pi top to HAT underside. |
| Pi supports | Four straight M2.5 supports, <=4.8 mm outside diameter | Match seated riser/socket height with measured spacers/shims. |
| FPGA | TE0712-03-81I36-A with standard connectors | Four M3 spacers; 8 mm HAT-to-module surface gap. |
| Geophone header / plug | Phoenix Contact 1803280 / 1803581 | Horizontal J90: 1 GEO+, 2 GEO-, 3 shield/GND. |

The geophone plug has 9.20 mm calculated lateral clearance to the module after
0.5 mm allowance. J90 opens parallel to the PCB toward native +Y. Reserve a
12 mm withdrawal stroke beyond the plug and clamp its shielded twisted pair
beside that corridor. The enclosure rotates the stack 180° so entry faces the
adjacent geophone. Release the cable clamp before unplugging.
Use the [R3 enclosure](../hw/mechanical/daqhat-01-case/README.md). Its Pi USB-C
and HDMI side faces the geophone bay, opposite GPIO; the adjacent wall admits
USB-A plugs. R1 printable geometry is superseded because it was mirrored.
The geophone is off-board and vertical; the enclosure holds its bare element in
the adjacent clamp. Mechanical coupling to the ground still needs qualification.

J1 uses the JLCPCB-selected 8.5 mm-body socket. Two external SSQ risers restore
clearance: 8.5 + 2 × 8.51 + 2.54 = **28.06 mm**. The risers are self-nesting;
4.93 mm tails satisfy the intermediate SSQ's 3.68–6.35 mm insertion range.
Check the upper riser's engagement in Megastar J1 and the lower riser's engagement
on the actual Pi, continuity of all 40 pins, retention and seated height before
fitting supports. These checks cannot be established from the enclosure render.
[Samtec dimensions](https://suddendocs.samtec.com/catalog_english/ssw_th.pdf).

The external riser was listed with quantity-one pricing and 591 units in stock
at [DigiKey](https://www.digikey.com/en/products/detail/samtec-inc/SSQ-120-02-G-D/1110847)
on 2026-09-27. It is separately purchased assembly hardware, not part of JLCPCB's
117-placement PCB BOM. Recheck stock before purchase.

## Checks and limits

`assembly_fit.py` checks four support envelopes against the actual underside
components, socket, modeled Pi ports and selected heatsink. It reserves 0.5 mm
for support clearance and 1 mm for component/port seating uncertainty.
The [generated report](../hw/groundlark-fpga-hat/boards/groundlark-daqhat-01/prefab-review.json)
records margins. Use supports at (3.5,3.5), (61.5,3.5), (3.5,52.5), (61.5,52.5)
mm. Trim through-hole tails to <=2 mm below the HAT; the model allows 0.2 mm extra.

Keep both risers and match the measured seated height. Removing cables does not qualify a shorter stack.
Actual mating, screws, cooler capacity, strain relief and sensor noise still need
a first-article check. The Pi and service envelopes are conceptual; the Trenz
model is the vendor's generic revision-03 STEP.

C95/C96 and D90 are underside geophone components; C90 is on the front.
ADC supply-pad and U101.4 link through-vias require epoxy-filled/copper-capped processing, as do the other
through-vias in this six-layer revision. Tenting alone does not meet this requirement.

See the [bench procedure](bench-procedure.md),
[Pi Case Fan brief](https://datasheets.raspberrypi.com/case-fan/case-fan-product-brief.pdf),
and [geophone plug](https://www.phoenixcontact.com/en-us/products/pcb-plug-mc-15-3-st-381-1803581).

## FPGA supply and enclosure clearance

Allow 140 × 56 mm for the revised carrier. Its original Pi and Trenz mounting
coordinates are unchanged. The R3 enclosure supports the power extension with four underside saddles and
board-edge stops. Their stiffness and printed fit remain unqualified.
J83 is at (95, 14.1) mm with its mouth facing -Y, opposite the geophone's +Y
exit. Its 9 × 14.4 × 11 mm body and the actual adapter plug/cable need clearance.
The R3 case is 159 × 118 × 75 mm. Its rear opening reserves up to 14 mm for
an adapter body, subject to the PCB-edge clearance in the enclosure guide.
A roof opening gives access to SW80. Updated illustrations show the wider board.
CAD clearance does not establish printed fit or thermal performance. Apply only
12 V ±5%, center-positive at J83. J130 separately accepts 8–18 V DC for the
TI-controlled Pi supply. Leave Pi USB-C power disconnected when using J130.
Remove the JP130 bench shunt before automatic supervision; MCU firmware and
battery configuration must first be implemented and qualified.

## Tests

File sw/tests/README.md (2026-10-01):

# Software validation

The runnable contract suite (`test_contract.py`) uses an independently specified
binary producer fixture and covers semantics, corruption and bounded framing.
Run `./lab.ps1 test -Profile software` from the repository root.

The acquisition, driver and Linux I/O suites run the actual application against
independent expectations: recordings, bus errors, time jumps, malformed frames,
queue limits, disconnects, a real pseudo-terminal and a hung subprocess. The
portable runner retains a bounded demo recording and replay summary.
See [the runtime guide](../../docs/sensor-software.md) for limits and commands.
`test_stimulus.py` checks independent physical/raw-count expectations, control
boundaries, deterministic noise, GNSS movement, timed faults and scenario export
followed by byte-identical regeneration through the actual CLI.

`test_hat_signals.py` exercises a fixed eight-second capture through production
Pi sensor drivers on modeled register/packet buses. It measures frequency, gain,
phase, gravity, gyro/tilt consistency, inter-IMU agreement, GNSS motion and sample
timing. Negative controls prove that physically wrong but well-framed data fail.
The software profile retains `hat-signals.ssrec` and `hat-signals.json`; the UI's
**Test selected board** button runs the same analyzer and displays its exact capture.
These thresholds apply to ideal models, not unqualified physical hardware.

`test_fifo.py` checks independent FIFO tag vectors, buffered sample preservation,
counter/timestamp wrap and concealed gaps, overrun rejection, recovery and the
driver-to-runtime-to-recording path. `test_deployment.py` compiles and merges the
Pi overlay with actual device-tree tools, checks five chip selects, refuses wrong
SPI bindings and exercises the GPIO event ABI. `test_measurements.py` checks
known moments, SI conversions and incompatible bench-comparison rejection.
None of these substitutes for live Pi/kernel/sensor qualification.

`test_utc.py` exercises GNSS timing configuration/readback, fragmented/corrupt
UBX, PPS association faults, leap/midnight guards and UTC-copy replay through the
real correlator. `test_bench.py` proves missing measurements/limits cannot pass,
fixed power limits reject violations, and changed evidence hashes are rejected.
See [UTC timing](../../docs/utc-timing.md) and [bench procedure](../../docs/bench-procedure.md).

Keep small deterministic input fixtures here. Put generated logs, traces and
coverage in the portable lab's disposable workspace. Reserve bounded waveform
capture for failures. Add runnable profiles when their implementations and
acceptance criteria exist; do not substitute placeholder passes for integration.

See the [simulation roadmap](../../docs/portable-lab.md#next-simulation-layers).

`test_geophone_timing.py` advances the ADC clock independently of the four-channel
polling loop, with I2C wire delays, clock tolerance and long scheduling stalls.
It checks raw-frame provenance, honest missing/timing fields and continuity
recovery without hardware reset storms. `acquisition-stress.json` retains the
six speed/clock cases; its throughput qualification remains false. The worker
tests also exercise the new conversion-gap exception over actual subprocess IPC.
These tests do not run on a Raspberry Pi or establish its maximum acquisition rate.

`test_drdy.py` exercises autonomous geophone capture, a paused IPC consumer,
bounded overflow with ordered unknown-loss markers, terminal faults after a
valid buffered prefix, falling-edge wire records and recording/recovery semantics.
It also rejects a stuck reader that would otherwise return empty healthy drains.
Physical ADC throughput and timing remain unqualified.

`test_fpga_link.py` checks independent framing/CRC, transfer failures at every
stage, late responses, stale results, dropped ACKs, readback faults, ownership
restoration and SIGTERM isolation. `test_fpga_evidence.py` injects timing and
report-coverage failures. The FPGA stage additionally runs the real Python client
against RTL pins, rather than relying only on a byte-level mock peer.
Physical qualification follows the [bench procedure](../../docs/bench-procedure.md).

`test_skylark.py` compiles the actual Skylark C drivers and encoder on Linux,
then validates their output with the independent Python protobuf/COBS receiver.
Fixtures cover startup missing data, checksums, ADC counter discontinuities,
absent devices, queue overflow, suspend/reconnect, and suspend during sensor
configuration. A two-page flash fixture interrupts each word erase and halfword
write around page rollover. The native stream also passes through standalone
USB capture and workbench replay. These checks do not emulate STM32 instructions
or establish physical USB timing. The profile additionally links an ARM image
and retains its ELF, binary, map and size/hash metadata.

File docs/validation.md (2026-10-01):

# Hardware validation and release gates

## Current DAQHAT-01 GNSS, calibration and power revision

The 140 × 56 mm board includes MAX-M10S-00B GNSS on I2C1, BCM24 PPS and a
side-facing SMA with a 3.3 V active-antenna supply. BCM4 remains geophone DRDY;
BCM6/13 retain the TI power-supervisor handshake. FPGA interfaces and the
independent adapter supply remain unchanged. Native checks report zero ERC
findings, zero DRC findings and zero unconnected items. The complete
13,010-track/via SES reproduces identical copper. Independent pin/no-connect,
power, RF geometry, fabrication and analog-layout checks pass.
The antenna limiter and local bypasses are routed; ISO1640 side 2 faces GNSS.
Pi rail calculations include resistor temperature drift and an unmeasured
±20 mV ripple/transient allowance. Thermal, short-circuit and timing acceptance
still require physical measurements.

Four underside calibration pads expose ground, geophone bias, analog supply and
data-ready without adding GPIO. Static calibration fits measured gain/offset
with instrument/configuration binding and retains raw counts. Local miniSEED
export preserves timing gaps and requires valid UTC intervals. See the
[calibration guide](calibration.md) and [timing limits](utc-timing.md).

The portable software checks run 253 tests successfully, including device-tree
checks, contract compatibility and FPGA loopback.
The workbench HTTP check and browser interaction check pass. Its Groundlark
signal bench passes 12/12 checks on 4,072 modeled samples from all six HAT sensors.
Infrasound uses the raw-response model; its Pi hardware driver remains pending.
Antenna open/short, lock-loss and missing-PPS controls preserve independent
sensor acquisition. Fault/recovery, replay and rejection of invalid UTC references
are covered. Supply checks include Pi temperature corners, invalid envelope
inputs, antenna fault current and the added GNSS bypass charge.
Modeled UTC correlation and miniSEED round trips do not qualify physical 1 ms
sample alignment; receiver RF, acquisition latency and filter delay need measurement.

The 159 × 118 × 75 mm R3 enclosure adds a side SMA slot. Geometric/component
checks, 560 native PCB underside checks and 25 enclosure fault tests pass.
The README renders use current CAD. Physical first-print fit remains pending.
The supervisor battery policy stays disabled with unset thresholds; target MCU
firmware and Pi shutdown integration remain pending.

The full portable run executes all 25 stages; 24 pass. Hardware regressions
report 186 tests, 13 failures and 16 errors from the existing
procurement-registry/source and supplier-pad mismatches, retaining
the existing assembly export hold. Exact GNSS and replacement-part stock
observations are recorded; full procurement and supplier-pad/rotation approval
remain pending. Ten focused GNSS pin/layout tests pass, including missing
bypass and ground-stitch faults. No physical
power, noise, thermal, battery or RF qualification is implied. See
[power operation](power-supplies.md#pi-supervisor-and-battery-input) and
[assembly status](jlcpcb-assembly.md).

## Reproducible checks and release limits

Run the [portable lab](portable-lab.md) for the three current hardware targets:
DAQHAT-01, Burrowlark and Skylark. It checks compiled circuits, independent
pin fixtures, native ERC/DRC, routing replay, supporting-circuit simulations
and the software profile. The shared sensor fixture is fixed independently of
current CAD and includes missing-pin and incorrect-supply fault tests.

See each product's guide for current electrical and mechanical limits.
[Shared SPICE models](../hw/shared/simulation/README.md) cover 18 sensor/USB
support-circuit cases; FPGA power and geophone checks are separate.
CAD and behavioral checks do not establish physical power, noise, timing,
USB, thermal, RF or assembly qualification. Fabrication approval remains
with the user. Follow the [bench procedure](bench-procedure.md) and preserve
missing measurements as unqualified results.

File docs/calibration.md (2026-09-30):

# Calibrating Groundlark DAQHAT-01

Groundlark supports **measured static gain and offset** for the three IMUs and
the geophone electronics. Raw SSREC and miniSEED counts are retained. Calibration
does not establish geophone velocity response, absolute timing, alignment or a
noise specification. No physical calibration coefficients ship with the board.

## Equipment and identification

Give each assembled HAT a permanent serial label and use that identifier as
`device_id` in its Pi acquisition profile. Keep it with the HAT if the Pi is
replaced. The identifier is operator assigned; software cannot detect a swapped
unlabelled HAT. Record the geophone serial, cable, mounting, board revision,
software revision, reference instrument/certificate, date, temperature and
uncertainties. Recalibrate after sensor or analog component replacement.

Use an isolated precision millivolt source and calibrated differential meter
for electronics; a rigid six-face fixture for accelerometers; and a calibrated
rate table for gyro scale. Reserve a shaker/reference seismometer and a common
time reference for dynamic response testing. Characterize warm-up by watching
offset and temperature stabilize; a fixed delay is not proof of stability.

## PCB probe access

TP90–TP93 are bare **1.5 mm underside copper pads**, with no fitted parts or
additional GPIO. The 140 × 56 mm outline and R3 enclosure dimensions are retained.
Access requires removing the HAT from its stack; there are no live probe holes
through the enclosure. Use an insulated fixture, inspect polarity before power,
and keep probes away from adjacent supply contacts.

Coordinates below use the native PCB outline origin, before mirroring the board
for an underside view. References are also visible on the KiCad fabrication layer.

| Pad | Signal | Native X, Y (mm) | Measurement |
| --- | --- | --- | --- |
| TP90 | GND | 6.60, 47.00 | Meter/logic reference |
| TP91 | GEO_VCM | 4.05, 47.00 | Filtered bias, approximately half AVDD |
| TP92 | GEO_AVDD | 7.30, 40.65 | ADC analog supply, approximately 3.3 V |
| TP93 | GEO_DRDY_N | 9.175, 38.50 | Active-low ADC data-ready, 3.3 V logic |

Use high-impedance probes and account for their loading. Remove them before
low-noise measurements. TP93 permits an external logic analyzer to measure ADC
cadence; it does not by itself associate samples with UTC or remove ADC delay.
The driver still uses polling. The pads add no DAC, analog switch or permanent
stimulus load to the sensitive differential input.

## 1. Geophone electronics: zero and DC gain

1. Disconnect the geophone at J90. Verify AVDD and VCM. Record the exact gain,
   reference, sample profile and supply conditions used for the calibration.
2. Fit a **floating differential short between J90 pins 1 and 2**. Leave pin 3
   as shield/ground. Do not connect either signal pin to ground: the PGA inputs
   need their mid-supply bias. Record settled offset/noise with the same
   acquisition path used in deployment. A short test measures electronics,
   not sensor sensitivity or cable continuity.
3. Replace the short with an isolated differential millivolt source. Preserve
   the board's common-mode bias, and measure the actual differential voltage
   at J90 while connected. A grounded bench generator is not automatically
   suitable. Include the source impedance, meter loading and common-mode
   uncertainty in the bench record.
4. Measure negative, near-zero and positive levels well inside the configured
   range. Gain 64 / 2.048 V reference has nominal **±32 mV** full scale. Start
   with levels near ±10 mV; verify actual voltage and common-mode compliance
   before capture. Use additional levels and repeats to check nonlinearity.
5. Capture each settled level separately, with no active calibration:

   ```sh
   python -m groundlark.cli live --profile instrument.json \
     --seconds 30 --output negative.ssrec --no-miniseed
   ```

   Use explicit filenames such as `zero.ssrec` and `positive.ssrec` for the
   other levels. `--no-miniseed` is optional for these bench recordings.
6. Inspect a settled sequence interval. These example sequence limits must
   exist and be free of loss in your recording:

   ```sh
   python -m groundlark.cli calibration-observe negative.ssrec \
     --device GL-HAT-001 --sensor 9 --field geophone_input_v \
     --first 1000 --last 8000
   ```

   The command reports raw mean, sample standard deviation, count,
   configuration hash and recording hash. Increase acquisition capacity or
   repeat the capture when loss occurs; do not interpolate a calibration gap.
7. Copy [the voltage fit template](../sw/pi/profiles/geophone-calibration.example.json).
   Fill in actual device identity, conditions, measured voltages, positive
   reference uncertainties, sequence limits and acceptance limits. `null`
   entries intentionally fail. Choose stability and residual limits from your
   measurement requirements before inspecting the fit.
8. Fit and review:

   ```sh
   python -m groundlark.cli calibration-fit voltage-fit.json --output GL-HAT-001-cal.json
   ```

   Paths in the specification are relative to that specification. The output
   is a calibration list plus `GL-HAT-001-cal.json.evidence.json`. Check all
   residuals, reference uncertainty, temperature and measured input ranges.
   Verify the result with additional levels/repeats not used in the fit.

The fitted `geophone_input_v` means J90 differential input volts. It includes
the assembled DC electronics path. Do not divide this by nominal geophone
sensitivity and label the result broadband ground velocity. Reconnect the
sensor after the electronics test and separately measure complete-chain noise.
TI's ADS122C04 internal short can diagnose ADC offset, but switching modes and
automatically restoring/discarding settling samples is not implemented here.
See [the TI datasheet](https://www.ti.com/lit/ds/symlink/ads122c04.pdf).

## 2. IMUs: six faces and known rotation

Use [the IMU template](../sw/pi/profiles/imu-calibration.example.json) for
sensor IDs 1, 2 and 3 independently. Hold the assembly still in +X, −X, +Y, −Y,
+Z and −Z orientations in the **ST package axes**. Record after settling in
each position. Use the measured local gravity magnitude and fixture alignment
uncertainty to specify reference vectors. The other two axes are near zero;
their uncertainty must include tilt. A nominal gravity value is an assumption,
not a traceable measurement.

The fitter solves each axis's scale and offset from all faces. This is a
diagonal affine fit, not a 3 × 3 misalignment correction. Validate at additional
orientations and repeat each face to expose seating or thermal errors. Six-face
static calibration only covers approximately ±1 g, not the full ±2 g range.

Stationary gyro measurements characterize bias. To fit gyro **scale**, use
known positive, zero and negative rates on each axis, with reference values in
rad/s and `angular_rate_rad_s` as the field. A zero-rate recording alone cannot
determine scale, so the fitter rejects it. A temperature fit requires at least
three measured temperatures in kelvin; it does not compensate acceleration or
gyro drift with temperature. Reference methods are described in this
[MEMS calibration study](https://www.mdpi.com/1424-8220/12/7/9448).

## 3. Apply and preserve the result

```sh
python -m groundlark.cli live --profile instrument.json \
  --calibrations GL-HAT-001-cal.json --seconds 30 --output calibrated.ssrec
```

The list may contain one active record per sensor. Combine the independently
reviewed sensor records into one JSON list for a complete HAT. If fitting more
than one quantity for an IMU, put those fields in the same fit specification;
do not provide two active records for the same sensor.

Version 2 records are content-addressed and bind to `device_id`, sensor ID and
the complete effective sensor configuration. They contain the evidence SHA-256
(canonical sorted compact JSON), gain/offset, and measured raw mean bounds.
Keep the evidence sidecar and source recordings with the calibration list.
The SSREC header includes the calibration list; it does not embed every source
recording or the full evidence sidecar. Archive those files together.

Raw values, quality flags, gaps and timestamps remain intact. A derived field
is absent outside its measured raw range; for a vector, all three axes must be
within range. Missing/fault samples have no derived values. The calibration ID
alone is not proof that a sample contains a usable SI field. Software does not
enforce temperature, mounting or elapsed-time validity: the operator must keep
operation within the documented conditions and recheck drift.

Older unbound affine records remain readable for compatibility. Prefer version
2 for new instruments. Simulation fixtures require `--allow-simulation` and
are identified as synthetic in their evidence; they cannot calibrate hardware.

Fit inputs are bounded to 3–12 observations per field, 32–100,000 consecutive
samples per interval and 256 MiB per recording. Unknown loss, saturation,
faults, incomplete runs, overlapping reference intervals and changed sensor
configurations fail. The report includes sample scatter and fit residuals;
these are **not** a combined metrological uncertainty budget. The positive
reference uncertainties are recorded, not used as regression weights.

miniSEED continues to store raw integer counts. Archive response metadata
alongside it; this DC fit is insufficient to generate a measured StationXML
velocity response. See [miniSEED storage](miniseed.md) and the
[FDSN response model](https://docs.fdsn.org/projects/stationxml/en/latest/response.html).

## 4. Qualify the complete instrument

- **Geophone dynamics:** compare the installed sensor/cable/electronics chain
  with a calibrated reference on a shaker or in a coherent colocated test.
  Measure amplitude at multiple frequencies and levels; fit sensitivity,
  resonance and damping with uncertainty. Validate using separate data.
  Measure the actual motion; shaker drive voltage is not a motion reference.
- **Timing and phase:** use a common reference clock or measured synchronization
  uncertainty. Characterize ADC/IMU filtering delay separately from capture
  time. The GNSS revision captures PPS, but physical sample UTC remains unqualified. Do not
  claim phase calibration by aligning traces visually.
- **Infrasound:** equalize both DLVR ports for zero, then compare pressure
  levels and frequency response with a calibrated low-pressure reference.
  Include the deployed tubing, inlet, wind filter and enclosure leakage. The
  current live acquisition and static fitter do not yet support this workflow.
- **Repeatability/noise:** repeat after warm-up, at deployment temperatures,
  with the FPGA off/on if fitted, and after reinstalling the assembly. Keep
  shorted-input noise separate from sensor/environment noise. Three IMUs on
  one board may share noise; do not assume independent self-noise.

These complete-chain methods follow the
[USGS Raspberry Shake evaluation](https://manual.raspberryshake.org/_downloads/RS4D-ASL-SRL.pdf)
and [PTB field calibration guide](https://www.ptb.de/empir2020/infra-auv/information-communication/publications/good-practice-guide/part-1-seismic-technology/field-calibration/).
AnyShake's [ADC calibration procedure](https://anyshake.org/docs/anyshake-explorer/E-C111G/advanced-operations/adc-calibration/)
is useful precedent for recording offsets, but its fixture and response must
not be transferred to this different front end. Keep the
[physical qualification checklist](bench-procedure.md) with each instrument's
measurements. PCB/ERC/DRC and software tests do not establish physical calibration.

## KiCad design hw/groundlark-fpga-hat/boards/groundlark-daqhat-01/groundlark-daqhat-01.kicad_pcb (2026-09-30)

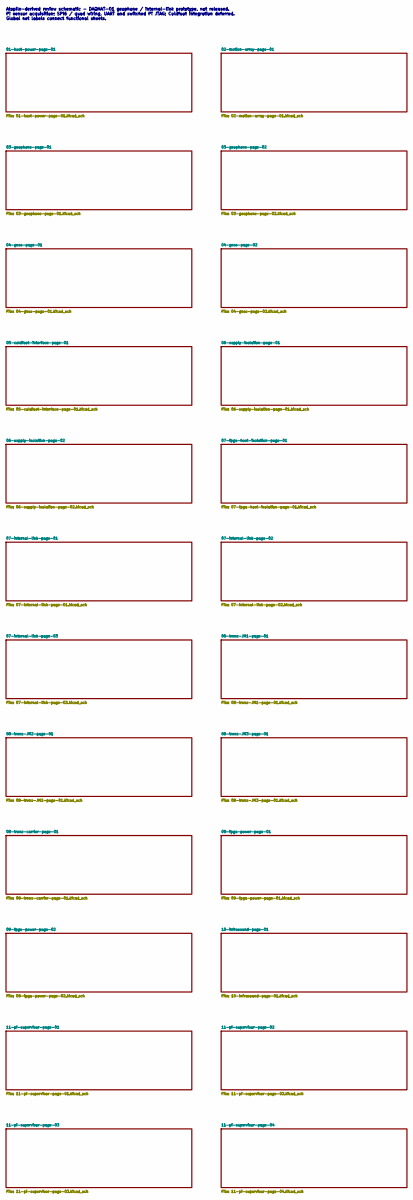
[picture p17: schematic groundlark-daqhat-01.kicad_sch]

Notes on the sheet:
Atopile-derived review schematic - DAQHAT-01 geophone / internal-link prototype, not released. Pi sensor acquisition; SPI6 / quad wiring, UART and switched Pi JTAG; Coldfoot integration deferred. Global net labels connect functional sheets.

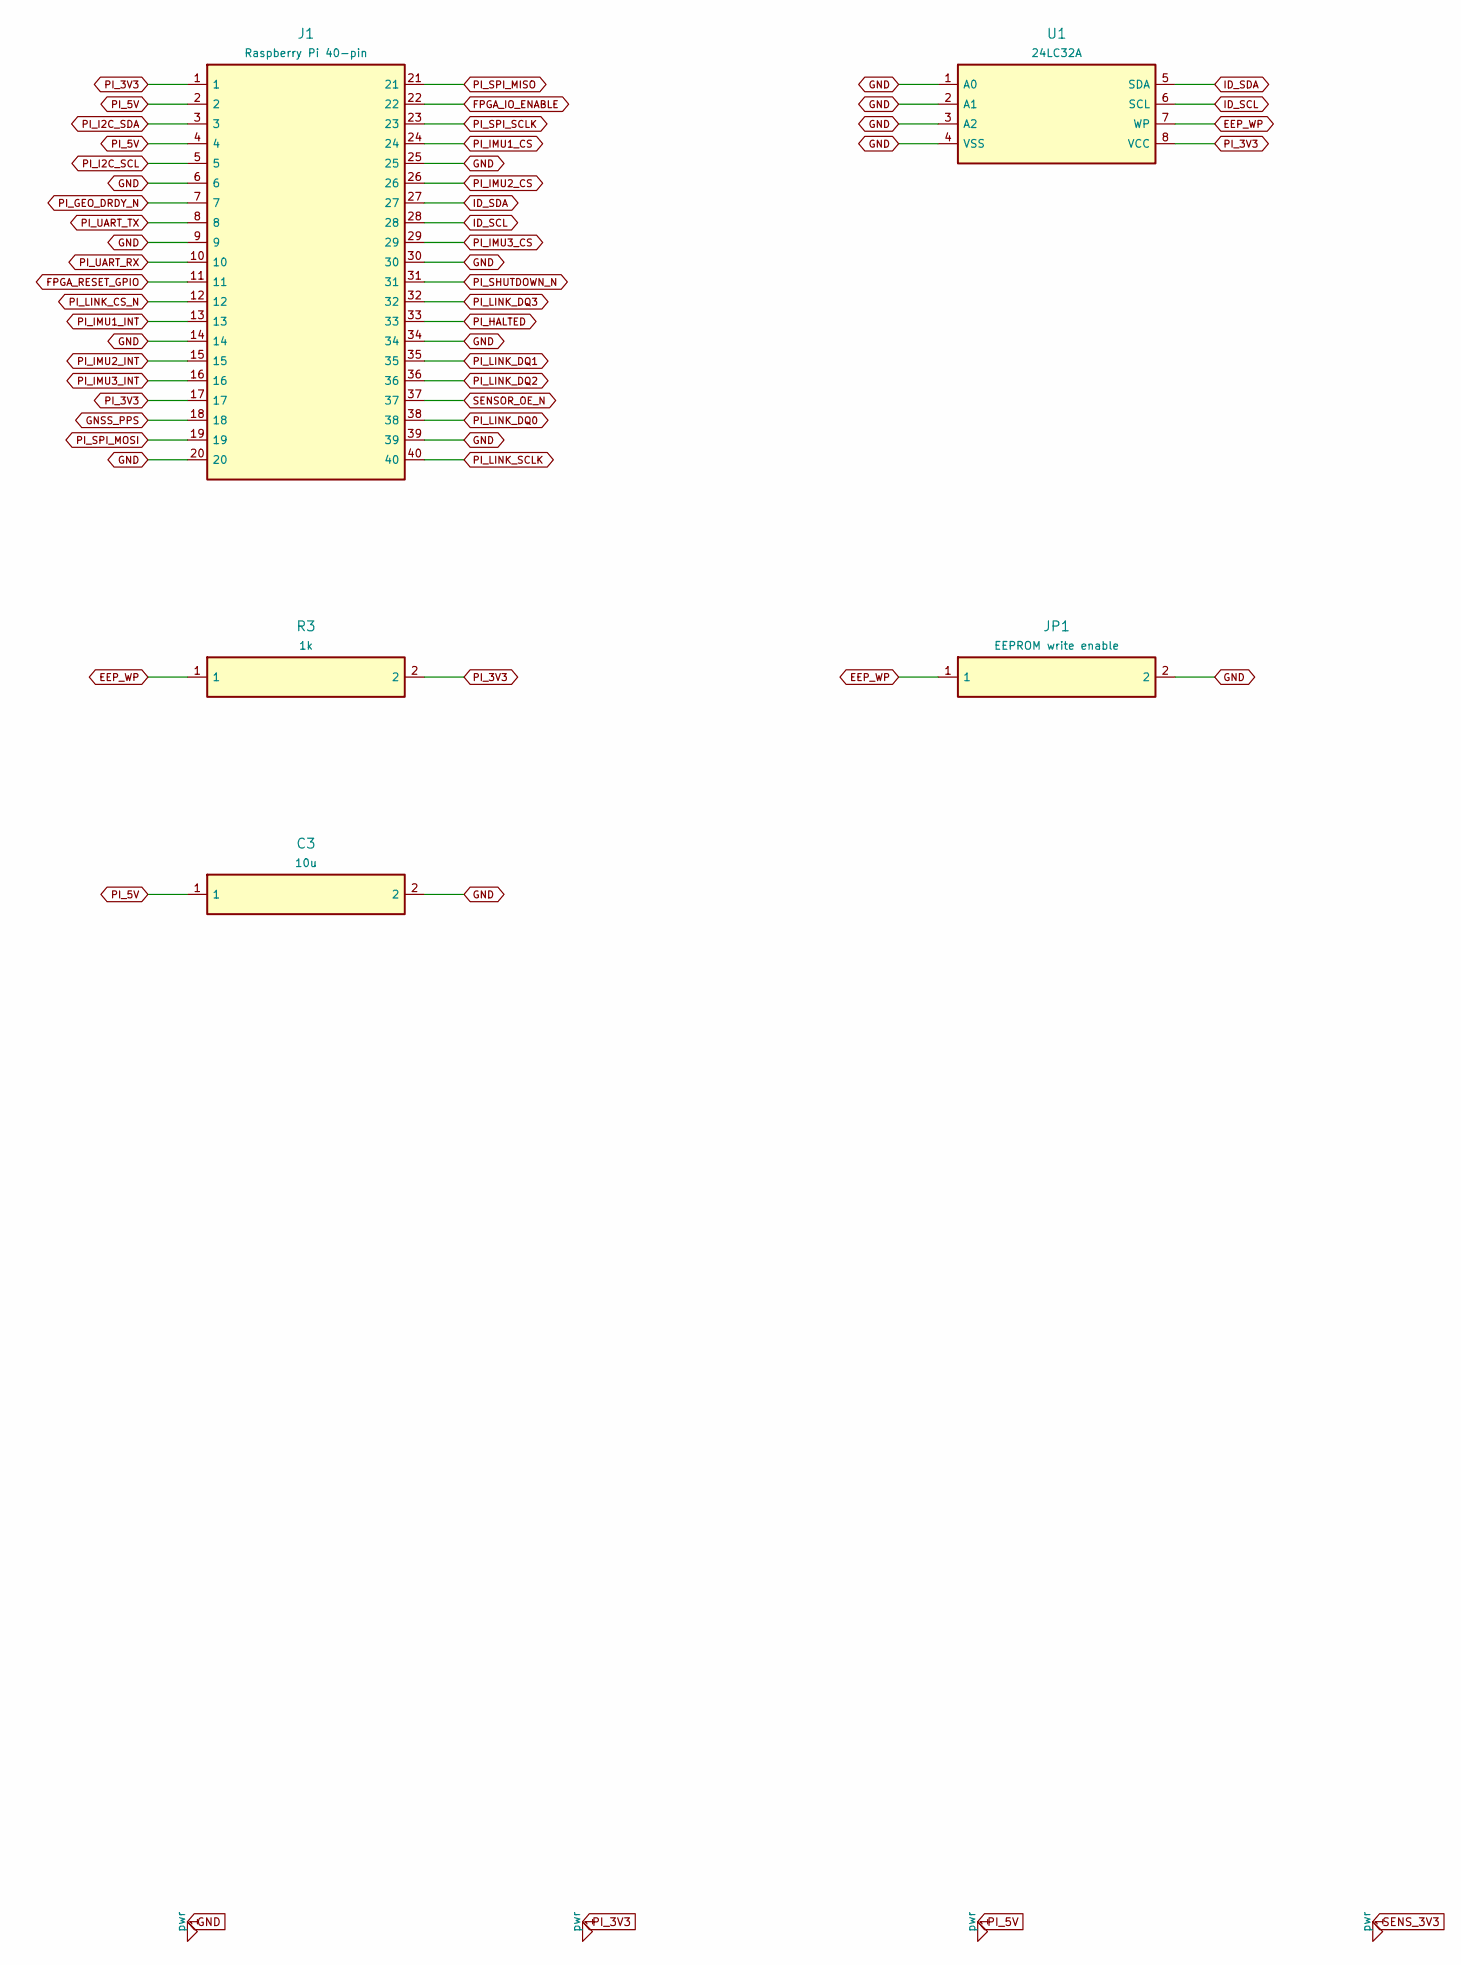
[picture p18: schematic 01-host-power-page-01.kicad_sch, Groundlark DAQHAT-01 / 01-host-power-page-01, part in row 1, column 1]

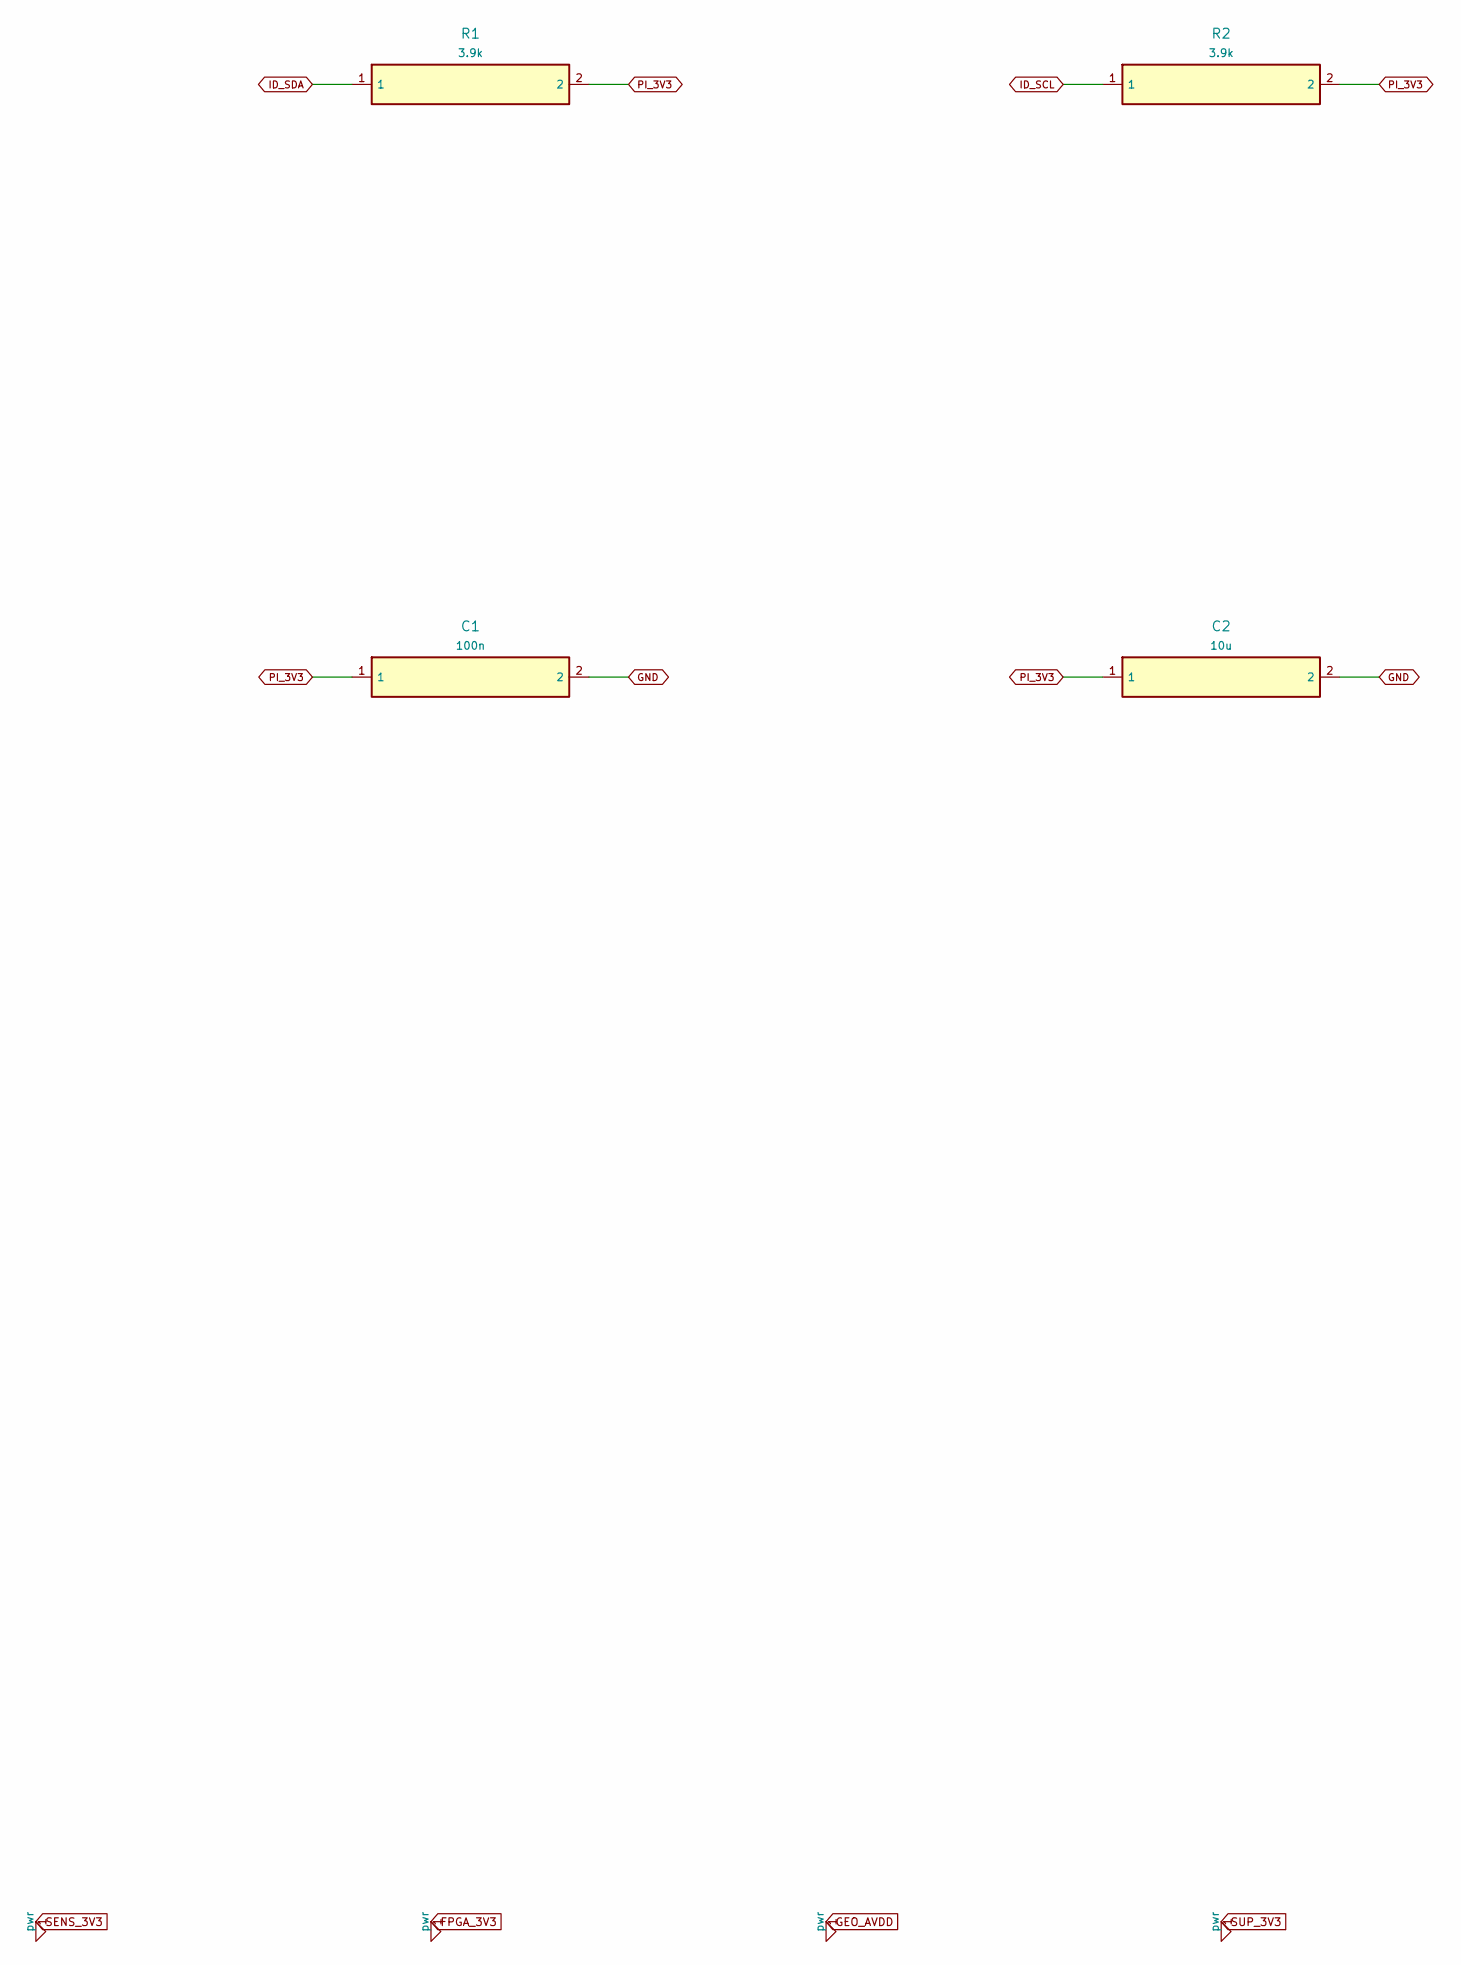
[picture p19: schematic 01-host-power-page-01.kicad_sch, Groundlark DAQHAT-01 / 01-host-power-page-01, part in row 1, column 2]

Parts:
C1: 100n; Capacitor_SMD__C_0603_1608Metric; MPN GRM188R71H104KA93D
C2, C3: 10u; Capacitor_SMD__C_0805_2012Metric; MPN GRM21BR61A106KE19L
J1: Raspberry Pi 40-pin; Connector_PinHeader_2.54mm__PinHeader_2x20_P2.54mm_Vertical; MPN Samtec ESQ-120-23-G-D
JP1: EEPROM write enable; Connector_PinHeader_2.54mm__PinHeader_1x02_P2.54mm_Vertical; MPN EEPROM write enable
R1, R2: 3.9k; Resistor_SMD__R_0603_1608Metric; MPN RC0603FR-073K9L
R3: 1k; Resistor_SMD__R_0603_1608Metric; MPN RC0603FR-071KL
U1: 24LC32A; Package_SO__SOIC-8_3.9x4.9mm_P1.27mm; MPN 24LC32A-I/SN

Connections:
EEP_WP: JP1.1, R3.1, U1.7 (WP)
FPGA_IO_ENABLE: J1.22; also elsewhere on the board
FPGA_RESET_GPIO: J1.11; also elsewhere on the board
GND: C1.2, C2.2, C3.2, J1.6, J1.9, J1.14, J1.20, J1.25, J1.30, J1.34, J1.39, JP1.2, U1.1 (A0), U1.2 (A1), U1.3 (A2), U1.4 (VSS); also elsewhere on the board
GNSS_PPS: J1.18; also elsewhere on the board
ID_SCL: J1.28, R2.1, U1.6 (SCL)
ID_SDA: J1.27, R1.1, U1.5 (SDA)
PI_3V3: C1.1, C2.1, J1.1, J1.17, R1.2, R2.2, R3.2, U1.8 (VCC); also elsewhere on the board
PI_5V: C3.1, J1.2, J1.4; also elsewhere on the board
PI_GEO_DRDY_N: J1.7; also elsewhere on the board
PI_HALTED: J1.33; also elsewhere on the board
PI_I2C_SCL: J1.5; also elsewhere on the board
PI_I2C_SDA: J1.3; also elsewhere on the board
PI_IMU1_CS: J1.24; also elsewhere on the board
PI_IMU1_INT: J1.13; also elsewhere on the board
PI_IMU2_CS: J1.26; also elsewhere on the board
PI_IMU2_INT: J1.15; also elsewhere on the board
PI_IMU3_CS: J1.29; also elsewhere on the board
PI_IMU3_INT: J1.16; also elsewhere on the board
PI_LINK_CS_N: J1.12; also elsewhere on the board
PI_LINK_DQ0: J1.38; also elsewhere on the board
PI_LINK_DQ1: J1.35; also elsewhere on the board
PI_LINK_DQ2: J1.36; also elsewhere on the board
PI_LINK_DQ3: J1.32; also elsewhere on the board
PI_LINK_SCLK: J1.40; also elsewhere on the board
PI_SHUTDOWN_N: J1.31; also elsewhere on the board
PI_SPI_MISO: J1.21; also elsewhere on the board
PI_SPI_MOSI: J1.19; also elsewhere on the board
PI_SPI_SCLK: J1.23; also elsewhere on the board
PI_UART_RX: J1.10; also elsewhere on the board
PI_UART_TX: J1.8; also elsewhere on the board
SENSOR_OE_N: J1.37; also elsewhere on the board

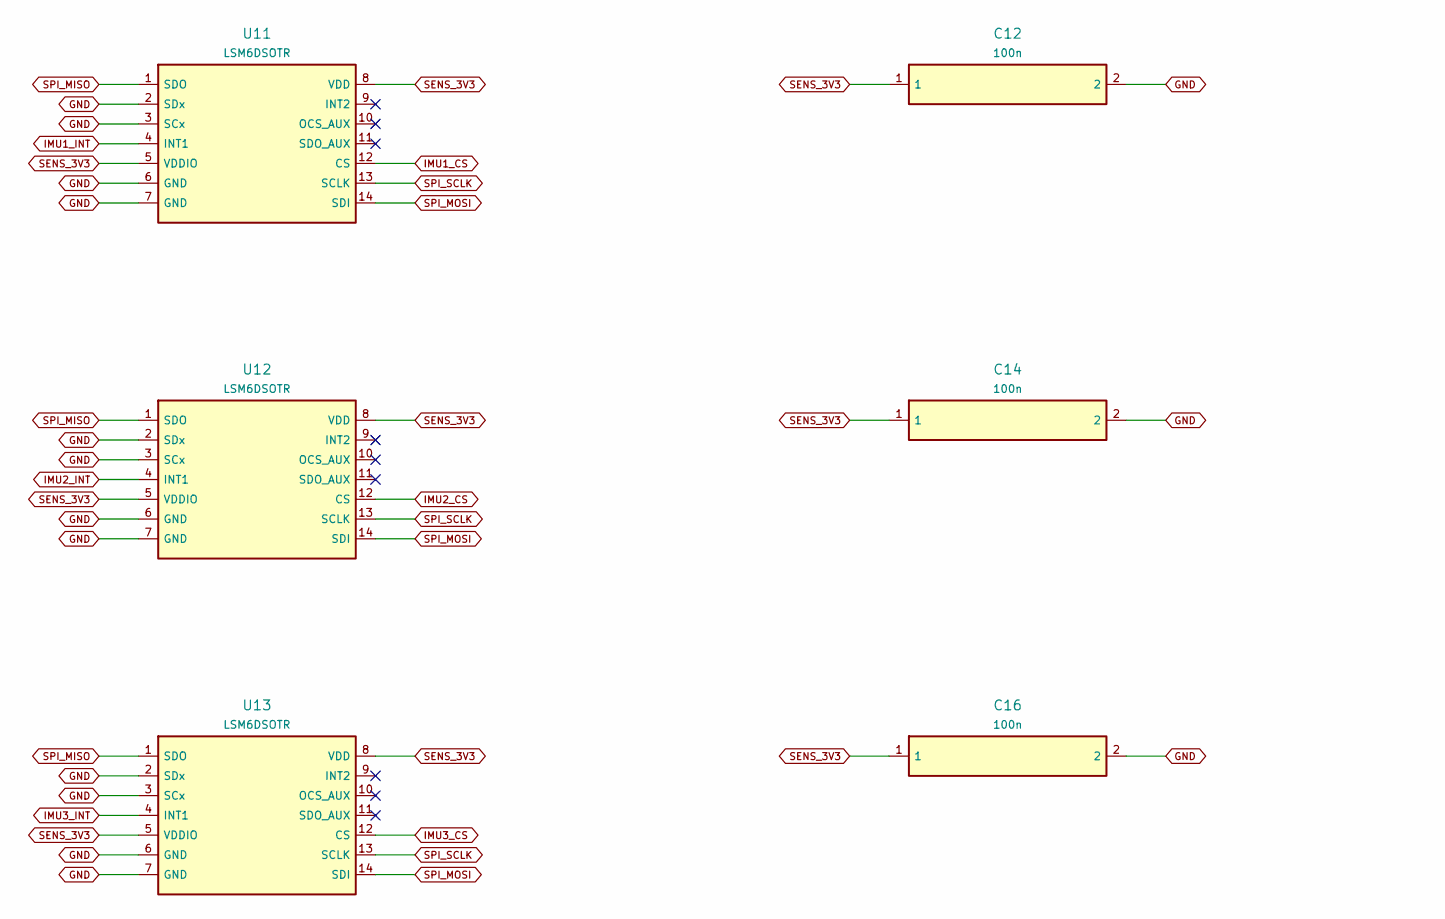
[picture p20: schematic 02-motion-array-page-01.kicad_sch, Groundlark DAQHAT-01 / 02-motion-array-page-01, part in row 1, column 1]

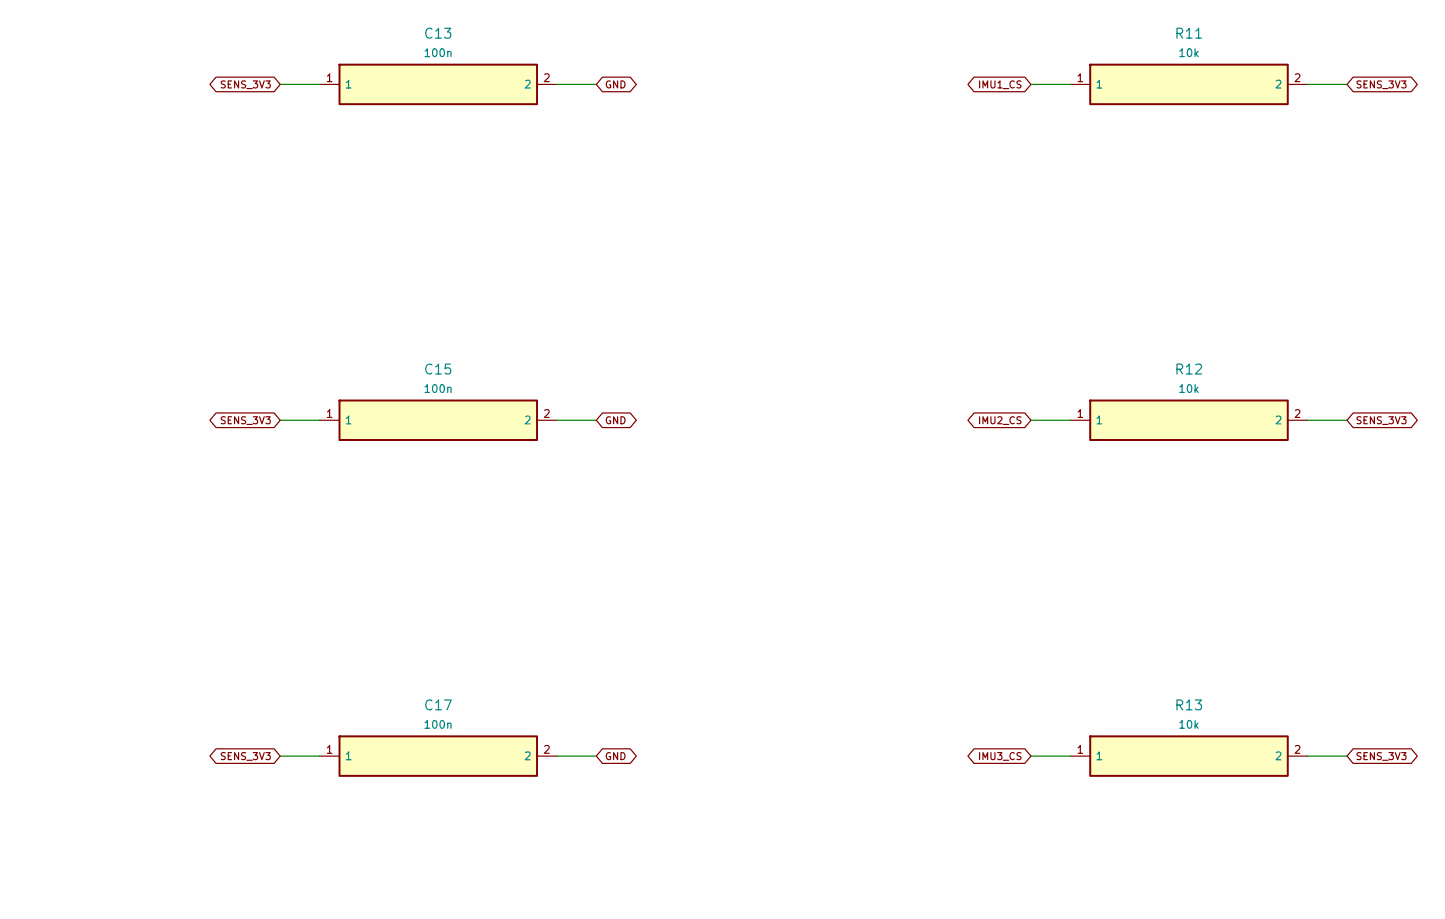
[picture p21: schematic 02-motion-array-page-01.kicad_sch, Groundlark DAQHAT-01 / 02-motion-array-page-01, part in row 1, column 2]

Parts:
C12, C13, C14, C15, C16, C17: 100n; Capacitor_SMD__C_0402_1005Metric; MPN GRM155R71C104KA88D
R11, R12, R13: 10k; Resistor_SMD__R_0603_1608Metric; MPN RC0603FR-0710KL
U11, U12, U13: LSM6DSOTR; Package_LGA__LGA-14_3x2.5mm_P0.5mm_LayoutBorder3x4y; MPN LSM6DSOTR

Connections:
GND: C12.2, C13.2, C14.2, C15.2, C16.2, C17.2, U11.2 (SDx), U11.3 (SCx), U11.6 (GND), U11.7 (GND), U12.2 (SDx), U12.3 (SCx), U12.6 (GND), U12.7 (GND), U13.2 (SDx), U13.3 (SCx), U13.6 (GND), U13.7 (GND); also elsewhere on the board
IMU1_CS: R11.1, U11.12 (CS); also elsewhere on the board
IMU1_INT: U11.4 (INT1); also elsewhere on the board
IMU2_CS: R12.1, U12.12 (CS); also elsewhere on the board
IMU2_INT: U12.4 (INT1); also elsewhere on the board
IMU3_CS: R13.1, U13.12 (CS); also elsewhere on the board
IMU3_INT: U13.4 (INT1); also elsewhere on the board
SENS_3V3: C12.1, C13.1, C14.1, C15.1, C16.1, C17.1, R11.2, R12.2, R13.2, U11.5 (VDDIO), U11.8 (VDD), U12.5 (VDDIO), U12.8 (VDD), U13.5 (VDDIO), U13.8 (VDD); also elsewhere on the board
SPI_MISO: U11.1 (SDO), U12.1 (SDO), U13.1 (SDO); also elsewhere on the board
SPI_MOSI: U11.14 (SDI), U12.14 (SDI), U13.14 (SDI); also elsewhere on the board
SPI_SCLK: U11.13 (SCLK), U12.13 (SCLK), U13.13 (SCLK); also elsewhere on the board
u11-9: U11.9 (INT2)
u11-10: U11.10 (OCS_AUX)
u11-11: U11.11 (SDO_AUX)
u12-9: U12.9 (INT2)
u12-10: U12.10 (OCS_AUX)
u12-11: U12.11 (SDO_AUX)
u13-9: U13.9 (INT2)
u13-10: U13.10 (OCS_AUX)
u13-11: U13.11 (SDO_AUX)

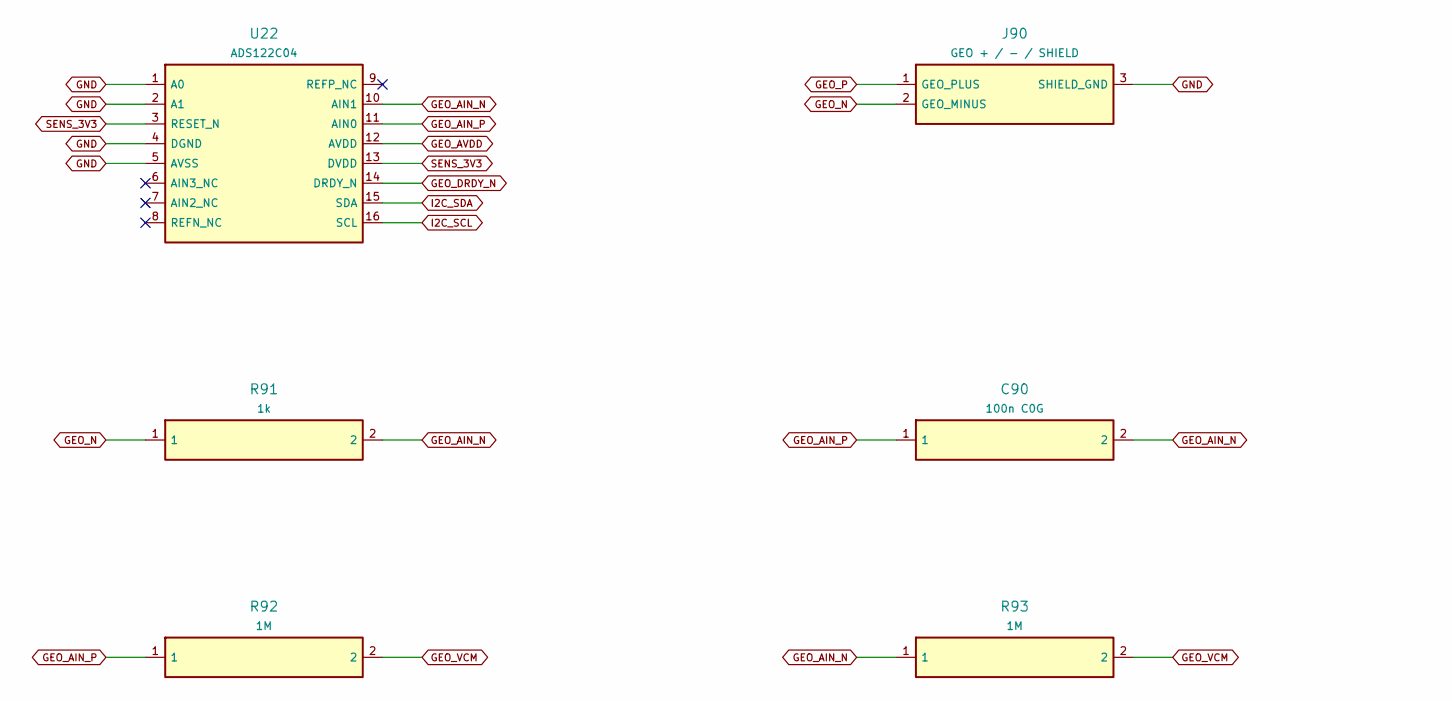
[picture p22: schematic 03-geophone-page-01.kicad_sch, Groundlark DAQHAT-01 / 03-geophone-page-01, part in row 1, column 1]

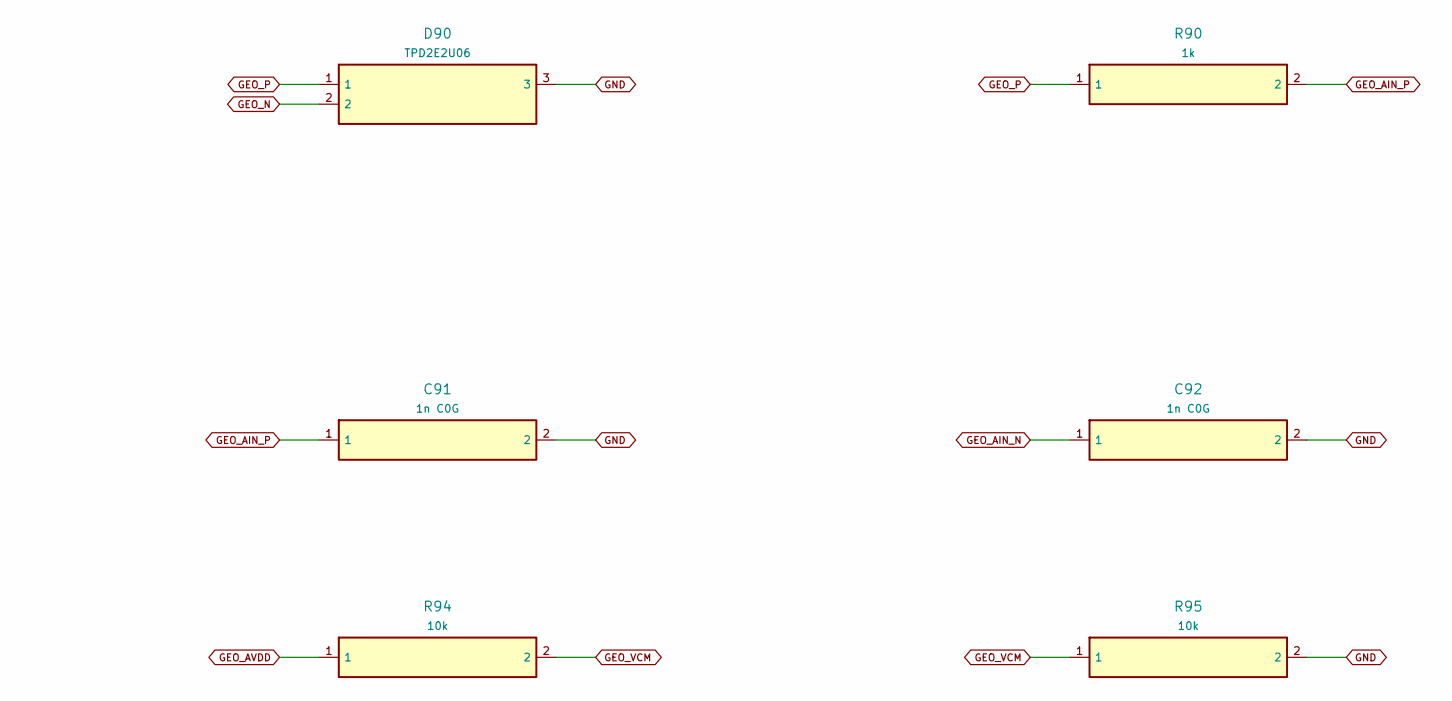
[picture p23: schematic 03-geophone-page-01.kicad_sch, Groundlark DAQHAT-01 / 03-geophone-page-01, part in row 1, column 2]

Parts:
C90: 100n C0G; Capacitor_SMD__C_1206_3216Metric; MPN C3216C0G1H104J160AA
C91, C92: 1n C0G; Capacitor_SMD__C_0603_1608Metric; MPN C0603C102J5GACTU
D90: TPD2E2U06; Package_TO_SOT_SMD__SOT-323_SC-70; MPN TPD2E2U06DCKR
J90: GEO + / - / SHIELD; Connector_Phoenix_MC__PhoenixContact_MC_1,5_3-G-3.81_1x03_P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; MPN 1803280
R90, R91: 1k; Resistor_SMD__R_0603_1608Metric; MPN RC0603FR-071KL
R92, R93: 1M; Resistor_SMD__R_0603_1608Metric; MPN RC0603FR-071ML
R94, R95: 10k; Resistor_SMD__R_0603_1608Metric; MPN RC0603FR-0710KL
U22: ADS122C04; Package_SO__TSSOP-16_4.4x5mm_P0.65mm; MPN ADS122C04IPWR

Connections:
GEO_AIN_N: C90.2, C92.1, R91.2, R93.1, U22.10 (AIN1)
GEO_AIN_P: C90.1, C91.1, R90.2, R92.1, U22.11 (AIN0)
GEO_AVDD: R94.1, U22.12 (AVDD); also elsewhere on the board
GEO_DRDY_N: U22.14 (DRDY_N); also elsewhere on the board
GEO_N: D90.2, J90.2 (GEO_MINUS), R91.1
GEO_P: D90.1, J90.1 (GEO_PLUS), R90.1
GEO_VCM: R92.2, R93.2, R94.2, R95.1; also elsewhere on the board
GND: C91.2, C92.2, D90.3, J90.3 (SHIELD_GND), R95.2, U22.1 (A0), U22.2 (A1), U22.4 (DGND), U22.5 (AVSS); also elsewhere on the board
I2C_SCL: U22.16 (SCL); also elsewhere on the board
I2C_SDA: U22.15 (SDA); also elsewhere on the board
SENS_3V3: U22.3 (RESET_N), U22.13 (DVDD); also elsewhere on the board
u22-6: U22.6 (AIN3_NC)
u22-7: U22.7 (AIN2_NC)
u22-8: U22.8 (REFN_NC)
u22-9: U22.9 (REFP_NC)

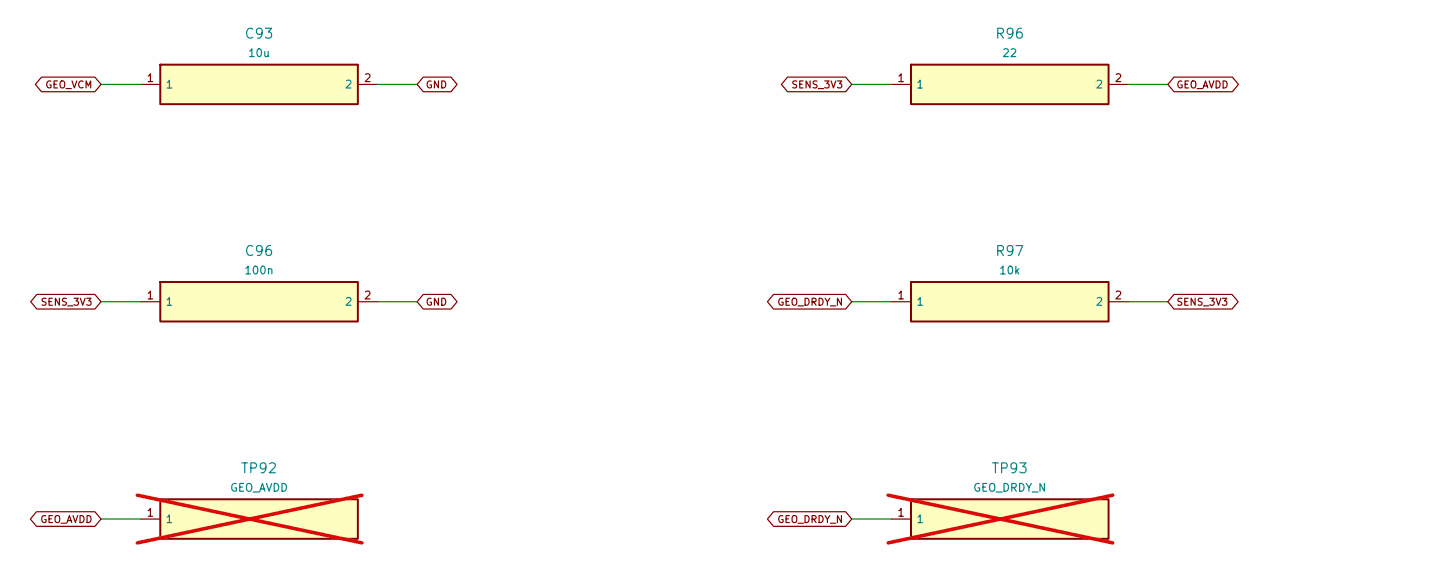
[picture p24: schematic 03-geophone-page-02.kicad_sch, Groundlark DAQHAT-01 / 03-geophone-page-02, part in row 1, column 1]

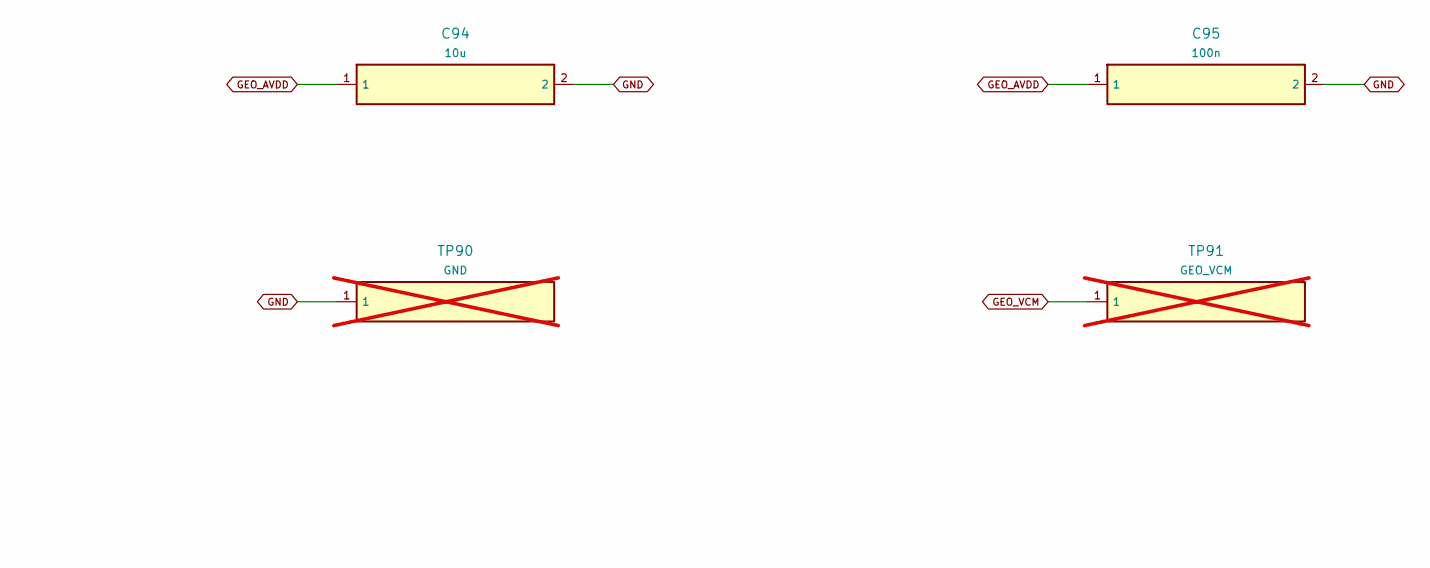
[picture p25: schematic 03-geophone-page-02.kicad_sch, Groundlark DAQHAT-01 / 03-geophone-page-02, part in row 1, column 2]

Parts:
C93, C94: 10u; Capacitor_SMD__C_0805_2012Metric; MPN GRM21BR61A106KE19L
C95, C96: 100n; Capacitor_SMD__C_0603_1608Metric; MPN GRM188R71H104KA93D
R96: 22; Resistor_SMD__R_0603_1608Metric; MPN RC0603FR-0722RL
R97: 10k; Resistor_SMD__R_0603_1608Metric; MPN RC0603FR-0710KL
TP90: GND; TestPoint__TestPoint_Pad_D1.5mm; MPN PCB copper; not fitted
TP91: GEO_VCM; TestPoint__TestPoint_Pad_D1.5mm; MPN PCB copper; not fitted
TP92: GEO_AVDD; TestPoint__TestPoint_Pad_D1.5mm; MPN PCB copper; not fitted
TP93: GEO_DRDY_N; TestPoint__TestPoint_Pad_D1.5mm; MPN PCB copper; not fitted

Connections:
GEO_AVDD: C94.1, C95.1, R96.2, TP92.1; also elsewhere on the board
GEO_DRDY_N: R97.1, TP93.1; also elsewhere on the board
GEO_VCM: C93.1, TP91.1; also elsewhere on the board
GND: C93.2, C94.2, C95.2, C96.2, TP90.1; also elsewhere on the board
SENS_3V3: C96.1, R96.1, R97.2; also elsewhere on the board

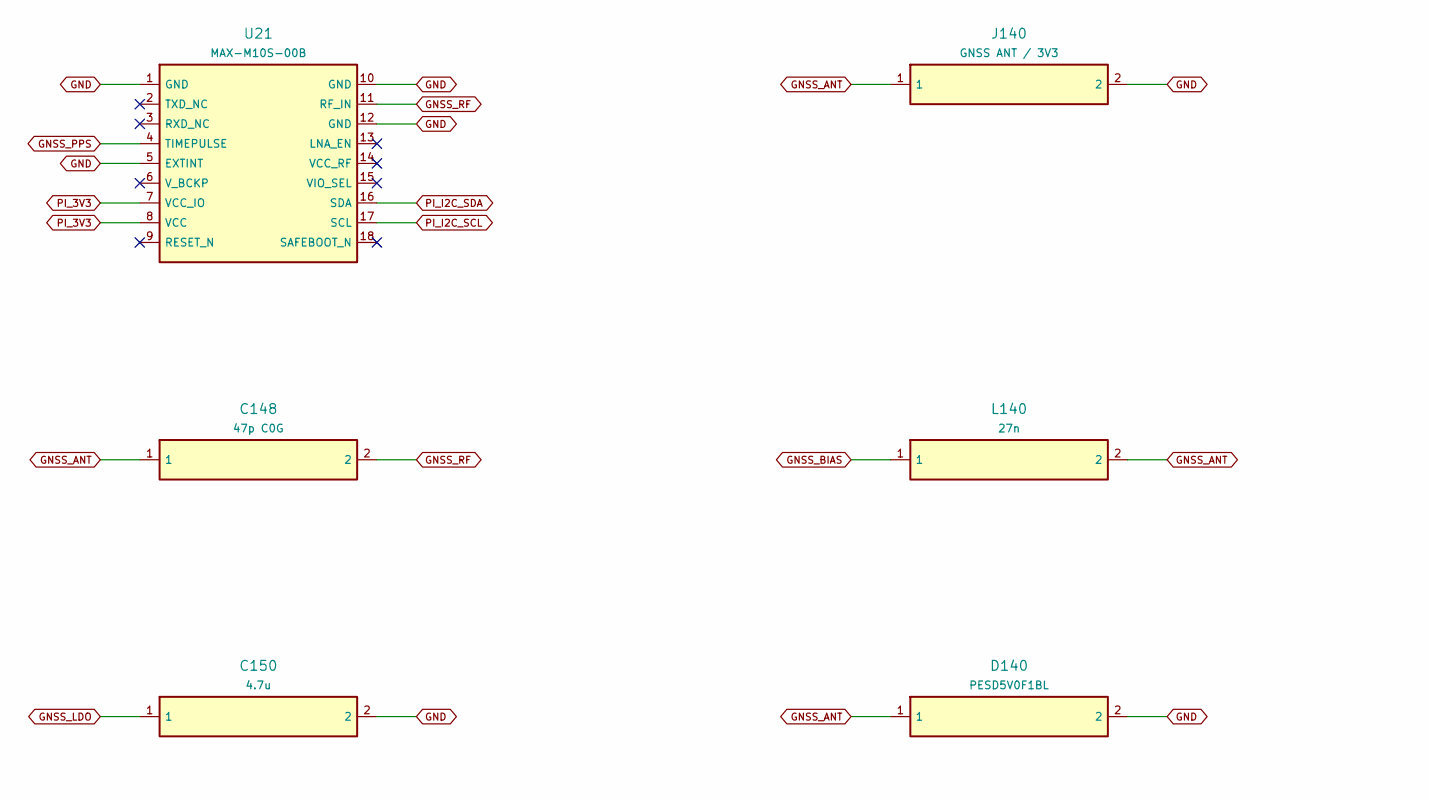
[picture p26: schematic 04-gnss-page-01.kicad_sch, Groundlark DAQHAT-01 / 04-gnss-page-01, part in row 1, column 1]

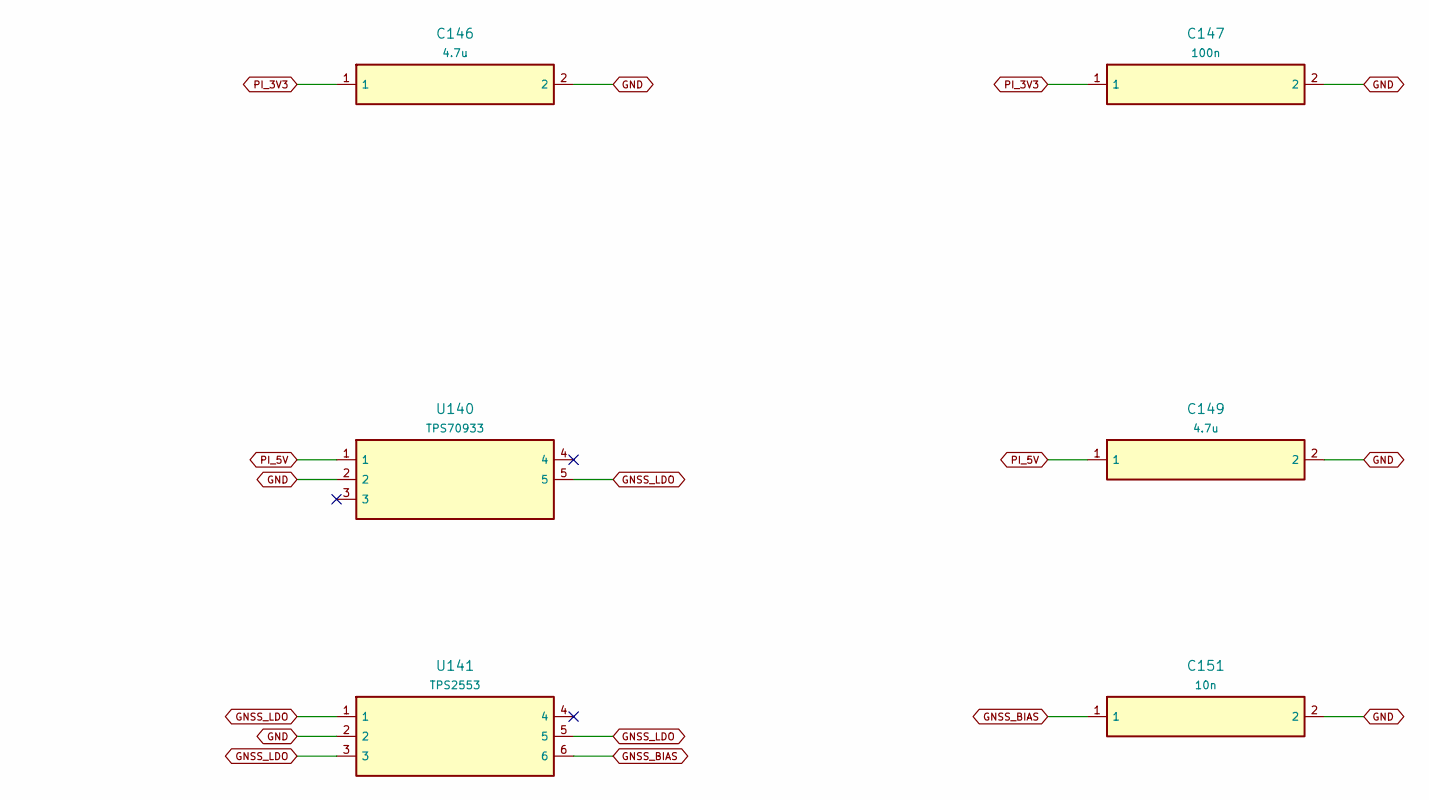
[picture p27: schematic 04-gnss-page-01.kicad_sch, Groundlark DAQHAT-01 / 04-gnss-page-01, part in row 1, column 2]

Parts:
C146, C149, C150: 4.7u; Capacitor_SMD__C_0805_2012Metric; MPN GRM21BR71C475KA73L
C147: 100n; Capacitor_SMD__C_0603_1608Metric; MPN GRM188R71H104KA93D
C148: 47p C0G; GNSS_C0402; MPN GRM1555C1H470JA01D
C151: 10n; SUP_C_0603_1608Metric; MPN GRM188R71H103KA01D
D140: PESD5V0F1BL; GNSS_SOD882; MPN PESD5V0F1BL,315
J140: GNSS ANT / 3V3; GNSS_HL_SMA_KWE_02; MPN HL-SMA-KWE-02
L140: 27n; GNSS_L0402; MPN LQW15AN27NJ00D
U21: MAX-M10S-00B; RF_GPS__ublox_MAX; MPN MAX-M10S-00B
U140: TPS70933; SUP_SOT-23-5; MPN TPS70933DBVR
U141: TPS2553; GNSS_SOT23_6; MPN TPS2553DBVR

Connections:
GND: C146.2, C147.2, C149.2, C150.2, C151.2, D140.2, J140.2, U21.1 (GND), U21.5 (EXTINT), U21.10 (GND), U21.12 (GND), U140.2, U141.2; also elsewhere on the board
GNSS_ANT: C148.1, D140.1, J140.1, L140.2
GNSS_BIAS: C151.1, L140.1, U141.6
GNSS_FAULT_NC: U141.4
GNSS_LDO: C150.1, U140.5, U141.1, U141.3, U141.5; also elsewhere on the board
GNSS_PPS: U21.4 (TIMEPULSE); also elsewhere on the board
GNSS_RF: C148.2, U21.11 (RF_IN)
PI_3V3: C146.1, C147.1, U21.7 (VCC_IO), U21.8 (VCC); also elsewhere on the board
PI_5V: C149.1, U140.1; also elsewhere on the board
PI_I2C_SCL: U21.17 (SCL); also elsewhere on the board
PI_I2C_SDA: U21.16 (SDA); also elsewhere on the board
u21-2: U21.2 (TXD_NC)
u21-3: U21.3 (RXD_NC)
u21-6: U21.6 (V_BCKP)
u21-9: U21.9 (RESET_N)
u21-13: U21.13 (LNA_EN)
u21-14: U21.14 (VCC_RF)
u21-15: U21.15 (VIO_SEL)
u21-18: U21.18 (SAFEBOOT_N)
u140-3: U140.3
u140-4: U140.4

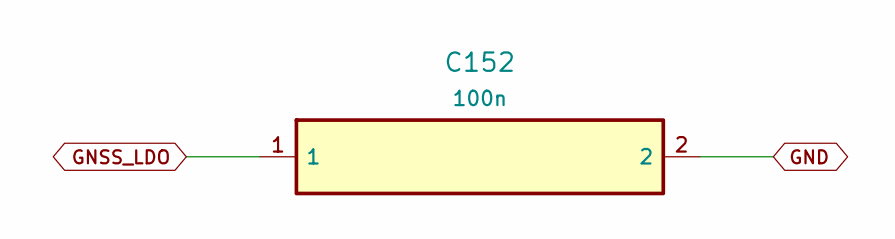
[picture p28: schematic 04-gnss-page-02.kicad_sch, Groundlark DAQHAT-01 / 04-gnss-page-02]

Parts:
C152: 100n; Capacitor_SMD__C_0603_1608Metric; MPN GRM188R71H104KA93D

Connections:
GND: C152.2; also elsewhere on the board
GNSS_LDO: C152.1; also elsewhere on the board

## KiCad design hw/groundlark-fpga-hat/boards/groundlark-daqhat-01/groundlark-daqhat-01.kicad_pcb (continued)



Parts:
C40: 10u; Capacitor_SMD__C_0805_2012Metric; MPN GRM21BR61A106KE19L
C41, C43, C44, C45, C46, C47: 100n; Capacitor_SMD__C_0603_1608Metric; MPN GRM188R71H104KA93D
C42: 22u; Capacitor_SMD__C_1206_3216Metric; MPN GRM31CR61A226KE19L
R50: 10k; Resistor_SMD__R_0603_1608Metric; MPN RC0603FR-0710KL
U40: TLV1117LV33DCYR; Package_TO_SOT_SMD__SOT-223-3_TabPin2; MPN TLV1117LV33DCYR
U41, U42: SN74LVC8T245PWR; Package_SO__TSSOP-24_4.4x7.8mm_P0.65mm; MPN SN74LVC8T245PWR

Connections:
GEO_DRDY_N: U42.16 (B6); also elsewhere on the board
GND: C40.2, C41.2, C42.2, C43.2, C44.2, C45.2, C46.2, C47.2, U40.1 (GND), U41.8 (A6), U41.9 (A7), U41.10 (A8), U41.11 (GND), U41.12 (GND), U41.13 (GND), U42.2 (DIR), U42.11 (GND), U42.12 (GND), U42.13 (GND), U42.14 (B8), U42.15 (B7), U42.17 (B5); also elsewhere on the board
IMU1_CS: U41.19 (B3); also elsewhere on the board
IMU1_INT: U42.20 (B2); also elsewhere on the board
IMU2_CS: U41.18 (B4); also elsewhere on the board
IMU2_INT: U42.19 (B3); also elsewhere on the board
IMU3_CS: U41.17 (B5); also elsewhere on the board
IMU3_INT: U42.18 (B4); also elsewhere on the board
PI_3V3: C44.1, C46.1, R50.2, U41.1 (VCCA), U41.2 (DIR), U42.1 (VCCA); also elsewhere on the board
PI_5V: C40.1, C41.1, U40.3 (IN); also elsewhere on the board
PI_GEO_DRDY_N: U42.8 (A6); also elsewhere on the board
PI_IMU1_CS: U41.5 (A3); also elsewhere on the board
PI_IMU1_INT: U42.4 (A2); also elsewhere on the board
PI_IMU2_CS: U41.6 (A4); also elsewhere on the board
PI_IMU2_INT: U42.5 (A3); also elsewhere on the board
PI_IMU3_CS: U41.7 (A5); also elsewhere on the board
PI_IMU3_INT: U42.6 (A4); also elsewhere on the board
PI_SPI_MISO: U42.3 (A1); also elsewhere on the board
PI_SPI_MOSI: U41.3 (A1); also elsewhere on the board
PI_SPI_SCLK: U41.4 (A2); also elsewhere on the board
SENSOR_OE_N: R50.1, U41.22 (OE_N), U42.22 (OE_N); also elsewhere on the board
SENS_3V3: C42.1, C43.1, C45.1, C47.1, U40.2 (OUT), U41.23 (VCCB), U41.24 (VCCB), U42.23 (VCCB), U42.24 (VCCB); also elsewhere on the board
SPI_MISO: U42.21 (B1); also elsewhere on the board
SPI_MOSI: U41.21 (B1); also elsewhere on the board
SPI_SCLK: U41.20 (B2); also elsewhere on the board
u41-14: U41.14 (B8)
u41-15: U41.15 (B7)
u41-16: U41.16 (B6)
u42-7: U42.7 (A5)
u42-9: U42.9 (A7)
u42-10: U42.10 (A8)

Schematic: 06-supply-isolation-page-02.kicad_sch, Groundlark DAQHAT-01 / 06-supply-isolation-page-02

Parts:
C48, C49: 100n; Capacitor_SMD__C_0603_1608Metric; MPN GRM188R71H104KA93D
R51: 100k; Resistor_SMD__R_0603_1608Metric; MPN RC0603FR-07100KL
R52, R53: 4.7k; Resistor_SMD__R_0603_1608Metric; MPN RC0603FR-074K7L
TP1: SENS_3V3; TestPoint__TestPoint_Pad_D1.5mm; MPN SENS_3V3
TP2: GND; TestPoint__TestPoint_Pad_D1.5mm; MPN GND
TP4: SENSOR_OE_N; TestPoint__TestPoint_Pad_D1.5mm; MPN SENSOR_OE_N
U43: ISO1640BDR; Package_SO__SOIC-8_3.9x4.9mm_P1.27mm; MPN ISO1640BDR

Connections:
GND: C48.2, C49.2, R51.2, TP2.1, U43.4 (GND1), U43.5 (GND2); also elsewhere on the board
I2C_SCL: R53.1, U43.3 (SCL1); also elsewhere on the board
I2C_SDA: R52.1, U43.2 (SDA1); also elsewhere on the board
PI_3V3: C49.1, U43.8 (VCC2); also elsewhere on the board
PI_I2C_SCL: U43.6 (SCL2); also elsewhere on the board
PI_I2C_SDA: U43.7 (SDA2); also elsewhere on the board
SENSOR_OE_N: TP4.1; also elsewhere on the board
SENS_3V3: C48.1, R52.2, R53.2, TP1.1, U43.1 (VCC1); also elsewhere on the board
SPI_MISO: R51.1; also elsewhere on the board

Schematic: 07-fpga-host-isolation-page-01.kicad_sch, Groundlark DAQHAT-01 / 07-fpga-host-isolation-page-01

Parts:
C75, C76, C77: 100n; Capacitor_SMD__C_0603_1608Metric; MPN GRM188R71H104KA93D
Q1: 2N7002; Package_TO_SOT_SMD__SOT-23; MPN 2N7002
R61: 47; Resistor_SMD__R_0603_1608Metric; MPN RC0603FR-0747RL
R62, R66: 100k; Resistor_SMD__R_0603_1608Metric; MPN RC0603FR-07100KL
R63, R64: 10k; Resistor_SMD__R_0603_1608Metric; MPN RC0603FR-0710KL
R65: 1k; Resistor_SMD__R_0603_1608Metric; MPN RC0603FR-071KL
U51: TXU0202DCUR; Package_SO__VSSOP-8_2.3x2mm_P0.5mm; MPN TXU0202DCUR
U52: TLV803EA30DBZR; Package_TO_SOT_SMD__SOT-23; MPN TLV803EA30DBZR

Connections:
FPGA_3V3: C76.1, C77.1, R63.2, R64.2, U51.7 (VCCB), U52.3 (VDD); also elsewhere on the board
FPGA_IO_ENABLE: R62.1, U51.6 (OE); also elsewhere on the board
FPGA_RESET_GATE: Q1.1 (G), R65.2, R66.1
FPGA_RESET_GPIO: R65.1; also elsewhere on the board
FPGA_RESET_N: Q1.3 (D), R64.1, U52.2 (RESET_N); also elsewhere on the board
FPGA_UART_DRIVE: R61.1, U51.8 (B1Y_OUT)
FPGA_UART_RX: R61.2, R63.1; also elsewhere on the board
FPGA_UART_TX: U51.1 (B2_IN); also elsewhere on the board
GND: C75.2, C76.2, C77.2, Q1.2 (S), R62.2, R66.2, U51.2 (GND), U52.1 (GND); also elsewhere on the board
PI_3V3: C75.1, U51.3 (VCCA); also elsewhere on the board
PI_UART_RX: U51.4 (A2Y_OUT); also elsewhere on the board
PI_UART_TX: U51.5 (A1_IN); also elsewhere on the board

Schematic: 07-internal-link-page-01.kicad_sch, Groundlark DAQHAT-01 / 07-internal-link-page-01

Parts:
C100, C101, C102, C103, C104, C105: 100n; Capacitor_SMD__C_0603_1608Metric; MPN GRM188R71H104KA93D
U100, U101: TMUX1574PWR; Package_SO__TSSOP-16_4.4x5mm_P0.65mm; MPN TMUX1574PWR
U102: TCA9534PWR; Package_SO__TSSOP-16_4.4x5mm_P0.65mm; MPN TCA9534PWR
U103: SN74LVC1G10DCKR; Package_TO_SOT_SMD__SOT-363_SC-70-6; MPN SN74LVC1G10DCKR
U104, U105: TLV809EA30DBZR; Package_TO_SOT_SMD__SOT-23; MPN TLV809EA30DBZR

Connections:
FPGA_3V3: C100.1, C101.1, C103.1, C105.1, U100.16 (VDD), U101.16 (VDD), U103.5 (VCC), U105.3 (VDD); also elsewhere on the board
FPGA_LINK_CS_N: U101.2 (S1A); also elsewhere on the board
FPGA_LINK_DQ0: U100.5 (S2A); also elsewhere on the board
FPGA_LINK_DQ1: U100.11 (S3A); also elsewhere on the board
FPGA_LINK_DQ2: U100.14 (S4A); also elsewhere on the board
FPGA_LINK_DQ3: U101.5 (S2A); also elsewhere on the board
FPGA_LINK_SCLK: U100.2 (S1A); also elsewhere on the board
GND: C100.2, C101.2, C102.2, C103.2, C104.2, C105.2, U100.8 (GND), U101.8 (GND), U101.9 (D3), U101.10 (S3B), U101.11 (S3A), U101.12 (D4), U101.13 (S4B), U101.14 (S4A), U102.1 (A0), U102.2 (A1), U102.3 (A2), U102.6 (P2), U102.7 (P3), U102.8 (GND), U102.9 (P4), U102.10 (P5), U102.11 (P6), U102.12 (P7), U103.2 (GND), U104.1 (GND), U105.1 (GND); also elsewhere on the board
JTAG_TCK: U100.3 (S1B); also elsewhere on the board
JTAG_TDI: U100.6 (S2B); also elsewhere on the board
JTAG_TDO: U100.10 (S3B); also elsewhere on the board
JTAG_TMS: U100.13 (S4B); also elsewhere on the board
LINK_ARMED_REQUEST: U103.1 (A); also elsewhere on the board
LINK_CS_N: U101.4 (D1); also elsewhere on the board
LINK_DQ0: U100.7 (D2); also elsewhere on the board
LINK_DQ1: U100.9 (D3); also elsewhere on the board
LINK_DQ2: U100.12 (D4); also elsewhere on the board
LINK_DQ3: U101.7 (D2); also elsewhere on the board
LINK_FPGA_GOOD: U103.6 (C), U105.2 (RESET_N); also elsewhere on the board
LINK_JTAG_SEL: U100.1 (SEL), U101.1 (SEL), U102.4 (P0_MODE); also elsewhere on the board
LINK_OE_N: U100.15 (EN_N), U101.15 (EN_N), U103.4 (Y); also elsewhere on the board
LINK_PI_GOOD: U103.3 (B), U104.2 (RESET_N); also elsewhere on the board
LINK_REQUEST: U102.5 (P1_ENABLE); also elsewhere on the board
LINK_SCLK: U100.4 (D1); also elsewhere on the board
PI_3V3: C102.1, C104.1, U102.16 (VCC), U104.3 (VDD); also elsewhere on the board
PI_I2C_SCL: U102.14 (SCL); also elsewhere on the board
PI_I2C_SDA: U102.15 (SDA); also elsewhere on the board
u101-3: U101.3 (S1B)
u101-6: U101.6 (S2B)
u102-13: U102.13 (INT_N)

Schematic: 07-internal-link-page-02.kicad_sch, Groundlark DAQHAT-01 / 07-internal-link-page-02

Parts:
R100, R101, R102, R103, R104, R105: 22; Resistor_SMD__R_0603_1608Metric; MPN RC0603FR-0722RL
R106, R107, R108, R109, R110, R111: 10k; Resistor_SMD__R_0603_1608Metric; MPN RC0603FR-0710KL

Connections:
FPGA_3V3: R108.2, R111.2; also elsewhere on the board
FPGA_LINK_CS_N: R111.1; also elsewhere on the board
GND: R106.2, R107.2, R109.2, R110.2; also elsewhere on the board
LINK_CS_N: R104.2; also elsewhere on the board
LINK_DQ0: R101.2; also elsewhere on the board
LINK_DQ1: R102.2; also elsewhere on the board
LINK_DQ2: R103.2; also elsewhere on the board
LINK_DQ3: R105.2; also elsewhere on the board
LINK_FPGA_GOOD: R110.1; also elsewhere on the board
LINK_JTAG_SEL: R106.1; also elsewhere on the board
LINK_OE_N: R108.1; also elsewhere on the board
LINK_PI_GOOD: R109.1; also elsewhere on the board
LINK_REQUEST: R107.1; also elsewhere on the board
LINK_SCLK: R100.2; also elsewhere on the board
PI_LINK_CS_N: R104.1; also elsewhere on the board
PI_LINK_DQ0: R101.1; also elsewhere on the board
PI_LINK_DQ1: R102.1; also elsewhere on the board
PI_LINK_DQ2: R103.1; also elsewhere on the board
PI_LINK_DQ3: R105.1; also elsewhere on the board
PI_LINK_SCLK: R100.1; also elsewhere on the board

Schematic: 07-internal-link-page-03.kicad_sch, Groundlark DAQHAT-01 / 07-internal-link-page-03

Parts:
C106: 100n; Capacitor_SMD__C_0603_1608Metric; MPN GRM188R71H104KA93D
R112, R114, R116, R117: 100k; Resistor_SMD__R_0603_1608Metric; MPN RC0603FR-07100KL
R113, R115: 10k; Resistor_SMD__R_0603_1608Metric; MPN RC0603FR-0710KL
U106: SN74LVC1G08DCKR; Package_TO_SOT_SMD__SOT-353_SC-70-5; MPN SN74LVC1G08DCKR

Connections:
FPGA_3V3: C106.1, R113.2, R115.2, U106.5 (VCC); also elsewhere on the board
FPGA_IO_ENABLE: U106.2 (B); also elsewhere on the board
FPGA_LINK_DQ2: R116.1; also elsewhere on the board
FPGA_LINK_DQ3: R117.1; also elsewhere on the board
FPGA_LINK_SCLK: R112.1; also elsewhere on the board
GND: C106.2, R112.2, R114.2, R116.2, R117.2, U106.3 (GND); also elsewhere on the board
JTAG_TCK: R114.1; also elsewhere on the board
JTAG_TDI: R115.1; also elsewhere on the board
JTAG_TMS: R113.1; also elsewhere on the board
LINK_ARMED_REQUEST: U106.4 (Y); also elsewhere on the board
LINK_REQUEST: U106.1 (A); also elsewhere on the board

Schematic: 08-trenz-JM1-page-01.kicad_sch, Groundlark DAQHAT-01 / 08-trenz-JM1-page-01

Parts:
J80: LSHM-150-04.0-L-DV-A-S-K-TR; TZ_TZ100; MPN LSHM-150-04.0-L-DV-A-S-K-TR

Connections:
3: J80.3
5: J80.5
9: J80.9
11: J80.11
15: J80.15
17: J80.17
18: J80.18
20: J80.20
21: J80.21
22: J80.22
23: J80.23
24: J80.24
26: J80.26
28: J80.28
32: J80.32
34: J80.34
35: J80.35
36: J80.36
37: J80.37
38: J80.38
39: J80.39
40: J80.40
41: J80.41
42: J80.42
44: J80.44
45: J80.45
46: J80.46
47: J80.47
48: J80.48
49: J80.49
50: J80.50
51: J80.51
52: J80.52
55: J80.55
56: J80.56
57: J80.57
58: J80.58
59: J80.59
60: J80.60
61: J80.61
62: J80.62
65: J80.65
66: J80.66
67: J80.67
68: J80.68
69: J80.69
70: J80.70
71: J80.71
72: J80.72
75: J80.75
76: J80.76
77: J80.77
78: J80.78
79: J80.79
80: J80.80
81: J80.81
82: J80.82
84: J80.84
85: J80.85
86: J80.86
87: J80.87
88: J80.88
91: J80.91
92: J80.92
93: J80.93
94: J80.94
95: J80.95
96: J80.96
97: J80.97
98: J80.98
99: J80.99
100: J80.100
FPGA_3V3: J80.10, J80.12, J80.13; also elsewhere on the board
FPGA_EN1: J80.27; also elsewhere on the board
FPGA_JTAGEN: J80.90; also elsewhere on the board
FPGA_MODE: J80.31
FPGA_NOSEQ: J80.8; also elsewhere on the board
FPGA_PGOOD: J80.29
FPGA_VIN: J80.2, J80.4, J80.6, J80.14, J80.16; also elsewhere on the board
GND: J80.1, J80.7, J80.19, J80.25, J80.30, J80.33, J80.43, J80.53, J80.54, J80.63, J80.64, J80.73, J80.74, J80.83, J80.89, J80.101; also elsewhere on the board

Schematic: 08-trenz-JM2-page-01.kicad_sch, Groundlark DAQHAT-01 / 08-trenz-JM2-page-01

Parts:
J81: LSHM-150-04.0-L-DV-A-S-K-TR; TZ_TZ100; MPN LSHM-150-04.0-L-DV-A-S-K-TR

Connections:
6: J81.6
16: J81.16
25: J81.25
27: J81.27
29: J81.29
30: J81.30
31: J81.31
33: J81.33
43: J81.43
53: J81.53
54: J81.54
63: J81.63
64: J81.64
73: J81.73
74: J81.74
83: J81.83
90: J81.90
FPGA_3V3: J81.2, J81.4, J81.8, J81.9, J81.10, J81.11, J81.92; also elsewhere on the board
FPGA_CONFIG_RESET_N: J81.17; also elsewhere on the board
FPGA_LINK_CS_N: J81.23; also elsewhere on the board
FPGA_LINK_DQ0: J81.22; also elsewhere on the board
FPGA_LINK_DQ1: J81.24; also elsewhere on the board
FPGA_LINK_DQ2: J81.26; also elsewhere on the board
FPGA_LINK_DQ3: J81.28; also elsewhere on the board
FPGA_LINK_SCLK: J81.21; also elsewhere on the board
FPGA_RESET_N: J81.13; also elsewhere on the board
FPGA_UART_RX: J81.12; also elsewhere on the board
FPGA_UART_TX: J81.14; also elsewhere on the board
FPGA_VIN: J81.1, J81.3, J81.5, J81.7; also elsewhere on the board
GND: J81.19, J81.39, J81.40, J81.49, J81.50, J81.59, J81.60, J81.69, J81.70, J81.79, J81.80, J81.89, J81.101; also elsewhere on the board
JTAG_TCK: J81.100; also elsewhere on the board
JTAG_TDI: J81.96; also elsewhere on the board
JTAG_TDO: J81.98; also elsewhere on the board
JTAG_TMS: J81.94; also elsewhere on the board
j81-15: J81.15
j81-18: J81.18
j81-20: J81.20
j81-32: J81.32
j81-34: J81.34
j81-35: J81.35
j81-36: J81.36
j81-37: J81.37
j81-38: J81.38
j81-41: J81.41
j81-42: J81.42
j81-44: J81.44
j81-45: J81.45
j81-46: J81.46
j81-47: J81.47
j81-48: J81.48
j81-51: J81.51
j81-52: J81.52
j81-55: J81.55
j81-56: J81.56
j81-57: J81.57
j81-58: J81.58
j81-61: J81.61
j81-62: J81.62
j81-65: J81.65
j81-66: J81.66
j81-67: J81.67
j81-68: J81.68
j81-71: J81.71
j81-72: J81.72
j81-75: J81.75
j81-76: J81.76
j81-77: J81.77
j81-78: J81.78
j81-81: J81.81
j81-82: J81.82
j81-84: J81.84
j81-85: J81.85
j81-86: J81.86
j81-87: J81.87
j81-88: J81.88
j81-91: J81.91
j81-93: J81.93
j81-95: J81.95
j81-97: J81.97
j81-99: J81.99

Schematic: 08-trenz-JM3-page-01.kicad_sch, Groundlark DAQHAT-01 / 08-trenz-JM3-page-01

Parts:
J82: LSHM-130-04.0-L-DV-A-S-K-TR; TZ_TZ60; MPN LSHM-130-04.0-L-DV-A-S-K-TR

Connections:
1: J82.1
2: J82.2
4: J82.4
7: J82.7
8: J82.8
10: J82.10
13: J82.13
14: J82.14
19: J82.19
GND: J82.5, J82.6, J82.11, J82.12, J82.17, J82.18, J82.23, J82.24, J82.29, J82.30, J82.35, J82.36, J82.45, J82.46, J82.61; also elsewhere on the board
j82-3: J82.3
j82-9: J82.9
j82-15: J82.15
j82-16: J82.16
j82-20: J82.20
j82-21: J82.21
j82-22: J82.22
j82-25: J82.25
j82-26: J82.26
j82-27: J82.27
j82-28: J82.28
j82-31: J82.31
j82-32: J82.32
j82-33: J82.33
j82-34: J82.34
j82-37: J82.37
j82-38: J82.38
j82-39: J82.39
j82-40: J82.40
j82-41: J82.41
j82-42: J82.42
j82-43: J82.43
j82-44: J82.44
j82-47: J82.47
j82-48: J82.48
j82-49: J82.49
j82-50: J82.50
j82-51: J82.51
j82-52: J82.52
j82-53: J82.53
j82-54: J82.54
j82-55: J82.55
j82-56: J82.56
j82-57: J82.57
j82-58: J82.58
j82-59: J82.59
j82-60: J82.60

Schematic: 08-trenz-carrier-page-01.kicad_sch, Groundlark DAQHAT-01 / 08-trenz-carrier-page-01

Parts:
JP80, JP81: TSW-102-07-G-S; TZ_TZ_JP; MPN TSW-102-07-G-S
R80, R81: 10k; Resistor_SMD__R_0603_1608Metric; MPN RC0603FR-0710KL

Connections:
FPGA_CONFIG_RESET_N: JP81.1; also elsewhere on the board
FPGA_EN1: JP80.1; also elsewhere on the board
FPGA_JTAGEN: R80.1; also elsewhere on the board
FPGA_NOSEQ: R81.1; also elsewhere on the board
GND: JP80.2, JP81.2, R80.2, R81.2; also elsewhere on the board

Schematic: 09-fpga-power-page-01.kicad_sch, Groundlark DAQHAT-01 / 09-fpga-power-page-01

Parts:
C80, C81, C82: 22u; Capacitor_SMD__C_1206_3216Metric; MPN GRM31CR61A226KE19L
C83: 100n; Capacitor_SMD__C_0603_1608Metric; MPN GRM188R71H104KA93D
C84, C85: 4.7u; Capacitor_SMD__C_0805_2012Metric; MPN GRM21BR71A475KA73L
D80: B340A; PWR_D_SMA; MPN B340A-13-F
D81: SMAJ15A; PWR_D_SMA; MPN SMAJ15A-13-F
F80: 0466002.NRHF; PWR_Fuse_1206_3216Metric; MPN 0466002.NRHF
J83: 12V DC / CENTER +; PWR_BarrelJack_CUI_PJ-102AH_Horizontal; MPN PJ-102AH
R120: 10k; PWR_R_0603_1608Metric; MPN RT0603BRD0710KL
U80: TPSM53603; PWR_Texas_B3QFN-14-1EP_5x5.5mm_P0.65mm; MPN TPSM53603RDAR

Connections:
BUCK_EN: U80.2 (EN); also elsewhere on the board
BUCK_FB: R120.2, U80.9 (FB); also elsewhere on the board
EXT_12V: F80.1, J83.1 (CENTER)
FPGA_3V3: C84.1, C85.1; also elsewhere on the board
FPGA_EN1: U80.6 (PGOOD); also elsewhere on the board
FPGA_VIN: C80.1, C81.1, C82.1, C83.1, R120.1, U80.7 (VOUT), U80.8 (VOUT); also elsewhere on the board
FUSED_12V: D80.2 (A), F80.2
GND: C80.2, C81.2, C82.2, C83.2, C84.2, C85.2, D81.2 (A), J83.2 (SLEEVE), U80.3 (NC_GND), U80.10 (NC_GND), U80.11 (NC_GND), U80.12 (AGND), U80.15 (PGND); also elsewhere on the board
PROTECTED_12V: D80.1 (K), D81.1 (K), U80.1 (VIN), U80.14 (VIN); also elsewhere on the board
j83-3: J83.3 (SWITCH_NC)
u80-4: U80.4 (DNC)
u80-5: U80.5 (DNC)
u80-13: U80.13 (V5V)

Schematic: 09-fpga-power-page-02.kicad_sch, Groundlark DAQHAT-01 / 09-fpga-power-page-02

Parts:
C86, C87: 10u; PWR_C_1206_3216Metric; MPN CGA5L1X7R1H106K160AC
C88: 100n; PWR_C_0603_1608Metric; MPN GRM188R71H104KA93D
C89: 47u; PWR_CP_Elec_6.3x7.7; MPN EEE-FK1V470P
C110, C111, C112: 22u; PWR_C_1210_3225Metric; MPN GRM32ER71E226KE15L
R121: 4.30k; PWR_R_0603_1608Metric; MPN RT0603BRD074K3L
R122: 100k; PWR_R_0603_1608Metric; MPN RC0603FR-07100KL
R123: 15k; PWR_R_0603_1608Metric; MPN RC0603FR-0715KL
R124: 10k; PWR_R_0603_1608Metric; MPN RT0603BRD0710KL
SW80: FPGA OFF / ON; PWR_SW_SPDT_PCM12; MPN PCM12SMTR

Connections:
BUCK_EN: R122.2, R123.1, SW80.2; also elsewhere on the board
BUCK_FB: R121.1; also elsewhere on the board
FPGA_EN1: R124.2; also elsewhere on the board
FPGA_VIN: C110.1, C111.1, C112.1, R124.1; also elsewhere on the board
GND: C86.2, C87.2, C88.2, C89.2, C110.2, C111.2, C112.2, R121.2, R123.2, SW80.1; also elsewhere on the board
PROTECTED_12V: C86.1, C87.1, C88.1, C89.1, R122.1; also elsewhere on the board
sw80-3: SW80.3

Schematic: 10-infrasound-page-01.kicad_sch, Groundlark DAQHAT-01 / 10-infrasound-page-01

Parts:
C24: 100n; Capacitor_SMD__C_0603_1608Metric; MPN GRM188R71H104KA93D
U23: DLVR-F50D; Groundlark__DLVR_E1BS; MPN DLVR-F50D-E1BS-I-NI3F

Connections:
GND: C24.2, U23.1 (GND); also elsewhere on the board
I2C_SCL: U23.4 (SCL); also elsewhere on the board
I2C_SDA: U23.3 (SDA); also elsewhere on the board
SENS_3V3: C24.1, U23.2 (VS_3V3); also elsewhere on the board

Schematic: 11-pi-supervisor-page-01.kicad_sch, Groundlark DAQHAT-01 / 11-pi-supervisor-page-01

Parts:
C130: 4.7u; SUP_C_0805_2012Metric; MPN GRM21BR71C475KA73L
C131, C132, C133: 10u; PWR_C_1206_3216Metric; MPN CGA5L1X7R1H106K160AC
C134: 100n; PWR_C_0603_1608Metric; MPN GRM188R71H104KA93D
C135: 47u; PWR_CP_Elec_6.3x7.7; MPN EEE-FK1V470P
D130: B340A; PWR_D_SMA; MPN B340A-13-F
D131: SMAJ18A; SUP_D_SMA; MPN SMAJ18A-13-F
F130: 4A fuse; SUP_Fuse_1206_3216Metric; MPN 0466004.NRHF
J130: PI BATTERY 8-18V; SUP_PhoenixContact_MC_1,5_2-G-3.81_1x02_P3.81mm_Horizontal; MPN 1803277
U131: TPS70933; SUP_SOT-23-5; MPN TPS70933DBVR
U132: TPSM53603; PWR_Texas_B3QFN-14-1EP_5x5.5mm_P0.65mm; MPN TPSM53603RDAR

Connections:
BAT_FUSED: D130.2, F130.2; also elsewhere on the board
BAT_INPUT: F130.1, J130.1 (+)
BAT_PROTECTED: C131.1, C132.1, C133.1, C134.1, C135.1, D130.1, D131.1, U131.1 (IN), U132.1 (VIN), U132.14 (VIN)
GND: C130.2, C131.2, C132.2, C133.2, C134.2, C135.2, D131.2, J130.2 (GND), U131.2 (GND), U132.3 (NC_GND), U132.10 (NC_GND), U132.11 (NC_GND), U132.12 (AGND), U132.15 (PGND); also elsewhere on the board
PI_BUCK_FB: U132.9 (FB); also elsewhere on the board
PI_RAW_5V: U132.7 (VOUT), U132.8 (VOUT); also elsewhere on the board
SUP_3V3: C130.1, U131.5 (OUT); also elsewhere on the board
SUP_RUN: U132.2 (EN); also elsewhere on the board
u131-3: U131.3 (EN_FLOAT)
u131-4: U131.4 (NC)
u132-4: U132.4 (DNC)
u132-5: U132.5 (DNC)
u132-6: U132.6 (PGOOD_NC)
u132-13: U132.13 (V5V_NC)

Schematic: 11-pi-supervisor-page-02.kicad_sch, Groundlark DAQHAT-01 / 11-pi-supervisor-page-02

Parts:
C136, C137, C138: 22u; PWR_C_1210_3225Metric; MPN GRM32ER71E226KE15L
C139: 10n; SUP_C_0603_1608Metric; MPN GRM188R71H103KA01D
C140: 10u; SUP_C_0805_2012Metric; MPN GRM21BR61C106KE15L
C141: 100n; PWR_C_0603_1608Metric; MPN GRM188R71H104KA93D
R130: 10k; PWR_R_0603_1608Metric; MPN RT0603BRD0710KL
R131: 2.43k; SUP_R_0603_1608Metric; MPN RT0603BRD072K43L
R132: 100k; PWR_R_0603_1608Metric; MPN RC0603FR-07100KL
R133: 2k; SUP_R_0603_1608Metric; MPN RC0603FR-072KL
U130: MSPM0L1106; SUP_QFN-32-1EP_5x5mm_P0.5mm_EP3.45x3.45mm; MPN MSPM0L1106TRHBR
U133: TPS22953; SUP_Texas_WSON10_DQC0010A; MPN TPS22953DQCR

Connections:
12: U130.12
GND: C136.2, C137.2, C138.2, C139.2, C140.2, C141.2, R131.2, R132.2, R133.2, U130.5 (VSS), U130.33 (GND), U133.5 (GND), U133.7 (PG_NC), U133.11 (GND); also elsewhere on the board
PI_5V: C140.1, R133.1, U133.9 (OUT), U133.10 (OUT); also elsewhere on the board
PI_BUCK_FB: R130.2, R131.1; also elsewhere on the board
PI_RAW_5V: C136.1, C137.1, C138.1, R130.1, U133.1 (IN), U133.2 (IN), U133.3 (BIAS), U133.8 (SNS); also elsewhere on the board
PI_SWITCH_CT: C139.1, U133.6 (CT)
SUP_3V3: C141.1, U130.4 (VDD); also elsewhere on the board
SUP_ACK_N: U130.9 (PA5_ACK_N); also elsewhere on the board
SUP_BAT_ADC: U130.31 (PA27_A0); also elsewhere on the board
SUP_CORE: U130.32 (VCORE); also elsewhere on the board
SUP_NRST: U130.3 (NRST); also elsewhere on the board
SUP_REQUEST: U130.8 (PA4_SHUTDOWN); also elsewhere on the board
SUP_RUN: R132.1, U133.4 (EN); also elsewhere on the board
SUP_RUN_DRIVE: U130.7 (PA3_RUN); also elsewhere on the board
SUP_SWCLK: U130.24 (PA20_SWCLK); also elsewhere on the board
SUP_SWDIO: U130.23 (PA19_SWDIO); also elsewhere on the board
u130-1: U130.1
u130-2: U130.2
u130-6: U130.6
u130-10: U130.10
u130-11: U130.11
u130-13: U130.13
u130-14: U130.14
u130-15: U130.15
u130-16: U130.16
u130-17: U130.17
u130-18: U130.18
u130-19: U130.19
u130-20: U130.20
u130-21: U130.21
u130-22: U130.22
u130-25: U130.25
u130-26: U130.26
u130-27: U130.27
u130-28: U130.28
u130-29: U130.29
u130-30: U130.30

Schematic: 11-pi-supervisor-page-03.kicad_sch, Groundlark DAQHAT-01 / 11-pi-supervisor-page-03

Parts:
C142: 10u; SUP_C_0805_2012Metric; MPN GRM21BR61C106KE15L
C143: 470n; SUP_C_0603_1608Metric; MPN GRM188R71C474KA88D
C144, C145: 10n; SUP_C_0603_1608Metric; MPN GRM188R71H103KA01D
Q130, Q131: 2N7002; SUP_SOT-23; MPN 2N7002,215
R134: 47k; SUP_R_0603_1608Metric; MPN RC0603FR-0747KL
R135: 1M; SUP_R_0603_1608Metric; MPN RT0603BRD071ML
R136: 150k; SUP_R_0603_1608Metric; MPN RT0603BRD07150KL
R137, R139: 100k; PWR_R_0603_1608Metric; MPN RC0603FR-07100KL
R138: 10k; PWR_R_0603_1608Metric; MPN RT0603BRD0710KL

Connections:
BAT_FUSED: R135.1; also elsewhere on the board
GND: C142.2, C143.2, C144.2, C145.2, Q130.2 (S), Q131.2 (S), R136.2, R137.2, R139.2; also elsewhere on the board
PI_3V3: R138.1; also elsewhere on the board
PI_HALTED: Q131.1 (G), R139.1; also elsewhere on the board
PI_SHUTDOWN_N: Q130.3 (D), R138.2; also elsewhere on the board
SUP_3V3: C142.1, R134.2; also elsewhere on the board
SUP_ACK_N: Q131.3 (D); also elsewhere on the board
SUP_BAT_ADC: C145.1, R135.2, R136.1; also elsewhere on the board
SUP_CORE: C143.1; also elsewhere on the board
SUP_NRST: C144.1, R134.1; also elsewhere on the board
SUP_REQUEST: Q130.1 (G), R137.1; also elsewhere on the board

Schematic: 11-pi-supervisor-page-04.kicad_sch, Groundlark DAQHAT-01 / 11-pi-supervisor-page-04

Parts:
J131: SWD / 3V3 REF; SUP_PinHeader_1x05_P1.27mm_Vertical; MPN FTS-105-01-L-S
JP130: BENCH RUN; SUP_PinHeader_1x02_P2.54mm_Vertical; MPN TSW-102-07-G-S
R140: 100k; PWR_R_0603_1608Metric; MPN RC0603FR-07100KL
R141: 10k; PWR_R_0603_1608Metric; MPN RT0603BRD0710KL

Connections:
GND: J131.2 (GND); also elsewhere on the board
SUP_3V3: J131.1 (VTREF), JP130.1, R140.1; also elsewhere on the board
SUP_ACK_N: R140.2; also elsewhere on the board
SUP_NRST: J131.5 (NRST); also elsewhere on the board
SUP_RUN: JP130.2, R141.2; also elsewhere on the board
SUP_RUN_DRIVE: R141.1; also elsewhere on the board
SUP_SWCLK: J131.3 (SWCLK); also elsewhere on the board
SUP_SWDIO: J131.4 (SWDIO); also elsewhere on the board



Board: 6 copper layers, 140.0 x 56.0 mm, 203 parts (44 on the bottom side), 109 nets.

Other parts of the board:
H1, H2, H3, H4: M2.5 NPTH; MountingHole__MountingHole_2.7mm_M2.5
H80, H81, H82, H83: M3 / 8 mm spacer; TZ_TZ_HOLE
J4: FPGA test UART/reset; Connector_PinHeader_2.54mm__PinHeader_1x04_P2.54mm_Vertical

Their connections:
FPGA_RESET_N: J4.4; also elsewhere on the board
FPGA_UART_RX: J4.2; also elsewhere on the board
FPGA_UART_TX: J4.3; also elsewhere on the board
GND: J4.1; also elsewhere on the board

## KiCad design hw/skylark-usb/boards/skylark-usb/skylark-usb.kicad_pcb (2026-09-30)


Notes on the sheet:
Atopile-derived review schematic - Skylark USB Rev A prototype, not released. PMS5003 / SGX SO2 and H2S / SHT40 / BMP390. Firmware and physical qualification pending. Global net labels connect functional sheets; raw working and auxiliary electrodes are acquired separately.

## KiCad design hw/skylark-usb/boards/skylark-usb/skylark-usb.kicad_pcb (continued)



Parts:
C1: 1uF; Capacitor_SMD__C_0603_1608Metric; MPN GRM188R71E105KA12D
C2: 4.7uF; Capacitor_SMD__C_0805_2012Metric; MPN GRM21BR71A475KA73L
D1, D2: USBLC6-2SC6; Package_TO_SOT_SMD__SOT-23-6; MPN USBLC6-2SC6
F1: 500mA PTC; Fuse_1206; MPN 1206L050YR
J1: TYPE-C-31-M-12; USB_C_HRO_TYPE-C-31-M-12; MPN TYPE-C-31-M-12
R1, R2: 5100R; Resistor_SMD__R_0603_1608Metric; MPN RC0603FR-075K1L
R3: 82000R; Resistor_SMD__R_0603_1608Metric; MPN RC0603FR-0782KL
R4: 100000R; Resistor_SMD__R_0603_1608Metric; MPN RT0603BRD07100KL
U2: AP2112K-3.3TRG1; Package_TO_SOT_SMD__SOT-23-5; MPN AP2112K-3.3TRG1
U3: TPS2553DBVR; Package_TO_SOT_SMD__SOT-23-6; MPN TPS2553DBVR

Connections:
A8: J1.A8
B8: J1.B8
CC1: D2.1 (IO1), D2.6 (IO1), J1.A5, R1.1
CC2: D2.3 (IO2), D2.4 (IO2), J1.B5, R2.1
GND: C1.2, C2.2, D1.2 (GND), D2.2 (GND), J1.A1B12, J1.B1A12, J1.S1, R1.2, R2.2, R3.2, R4.2, U2.2 (GND), U3.2 (GND); also elsewhere on the board
PM_5V: U3.6 (OUT); also elsewhere on the board
PM_EN: R4.1, U3.3 (EN); also elsewhere on the board
PM_FAULT_N: U3.5 (FAULT_N); also elsewhere on the board
PM_ILIM: R3.1, U3.4 (ILIM)
USB_5V: C1.1, F1.2 (OUT), U2.1 (VIN), U2.3 (EN), U3.1 (IN); also elsewhere on the board
USB_DM: D1.3 (IO2), D1.4 (IO2), J1.A7, J1.B7; also elsewhere on the board
USB_DP: D1.1 (IO1), D1.6 (IO1), J1.A6, J1.B6; also elsewhere on the board
USB_VBUS: D1.5 (VBUS), D2.5 (VBUS), F1.1 (IN), J1.A4B9, J1.B4A9
V3: C2.1, U2.5 (VOUT); also elsewhere on the board
u2-4: U2.4 (NC)



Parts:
C3: 100nF; Capacitor_SMD__C_0603_1608Metric; MPN GRM188R71H104KA93D
C4: 10uF; Capacitor_SMD__C_0805_2012Metric; MPN GRM21BR61A106KE19L
J2: BM08B-GHS-TBT; Connector_JST__JST_GH_BM08B-GHS-TBT_1x08-1MP_P1.25mm_Vertic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; MPN BM08B-GHS-TBT
Q5, Q6: 2N7002/HAMR; Package_TO_SOT_SMD__SOT-23; MPN 2N7002/HAMR
R5: 10000R; Resistor_SMD__R_0603_1608Metric; MPN RT0603BRD0710KL
R6, R7, R10, R11: 100000R; Resistor_SMD__R_0603_1608Metric; MPN RT0603BRD07100KL
R8, R9: 4700R; Resistor_SMD__R_0603_1608Metric; MPN RC0603FR-074K7L

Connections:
7: J2.7 (NC)
8: J2.8 (NC)
GND: C3.2, C4.2, J2.2 (GND), J2.MP (MOUNT), Q5.2 (S), Q6.2 (S), R6.2, R7.2, R11.2; also elsewhere on the board
PM_5V: C4.1, J2.1 (5V); also elsewhere on the board
PM_FAULT_N: R5.1; also elsewhere on the board
PM_RESET: Q6.1 (G), R7.1; also elsewhere on the board
PM_RESET_N: J2.6 (RESET_N), Q6.3 (D)
PM_RX: J2.4 (PMS_RX), R8.2
PM_SET_N: J2.3 (SET_N), Q5.3 (D)
PM_SLEEP: Q5.1 (G), R6.1; also elsewhere on the board
PM_TX: J2.5 (PMS_TX), R9.1
UART_RX: R9.2; also elsewhere on the board
UART_TX: R8.1; also elsewhere on the board
USB_5V: C3.1, R10.1; also elsewhere on the board
V3: R5.2; also elsewhere on the board
VBUS_SENSE: R10.2, R11.1; also elsewhere on the board


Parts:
C5: 100nF; Capacitor_SMD__C_0603_1608Metric; MPN GRM188R71H104KA93D

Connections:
GND: C5.2; also elsewhere on the board
VBUS_SENSE: C5.1; also elsewhere on the board



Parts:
C6, C7, C8, C9, C11: 100nF; Capacitor_SMD__C_0603_1608Metric; MPN GRM188R71H104KA93D
C10: 1uF; Capacitor_SMD__C_0603_1608Metric; MPN GRM188R71E105KA12D
J3: 20021111-00010T4LF; Connector_PinHeader_1.27mm__PinHeader_2x05_P1.27mm_Vertical; MPN 20021111-00010T4LF
R12, R13: 10000R; Resistor_SMD__R_0603_1608Metric; MPN RT0603BRD0710KL
SW1, SW2: TL3342F160QG; Button_Switch_SMD__SW_SPST_TL3342; MPN TL3342F160QG
U1: STM32F072CBT6; Package_QFP__LQFP-48_7x7mm_P0.5mm; MPN STM32F072CBT6

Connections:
3: U1.3 (PC14)
4: U1.4 (PC15)
5: U1.5 (PF0)
6: J3.6 (NC)
11: U1.11 (PA1)
20: U1.20 (PB2)
21: U1.21 (PB10)
22: U1.22 (PB11)
27: U1.27 (PB14)
28: U1.28 (PB15)
29: U1.29 (PA8)
30: U1.30 (PA9)
31: U1.31 (PA10)
38: U1.38 (PA15)
40: U1.40 (PB4)
41: U1.41 (PB5)
45: U1.45 (PB8)
46: U1.46 (PB9)
ADC_DRDY_N: U1.18 (PB0); also elsewhere on the board
ADC_RESET_N: U1.19 (PB1); also elsewhere on the board
ANA_EN: U1.25 (PB12); also elsewhere on the board
BOOT0: R13.1, SW2.1 (A), U1.44 (BOOT0)
CLAMP_HOLD: U1.26 (PB13); also elsewhere on the board
GND: C6.2, C7.2, C8.2, C9.2, C10.2, C11.2, J3.3 (GND), J3.5 (GND), J3.9 (GND), R13.2, SW1.2 (B), U1.8 (VSSA), U1.23 (VSS), U1.35 (VSS), U1.47 (VSS); also elsewhere on the board
NRST: C11.1, J3.10 (NRST), R12.1, SW1.1 (A), U1.7 (NRST)
PM_EN: U1.14 (PA4); also elsewhere on the board
PM_FAULT_N: U1.15 (PA5); also elsewhere on the board
PM_RESET: U1.17 (PA7); also elsewhere on the board
PM_SLEEP: U1.16 (PA6); also elsewhere on the board
SCL: U1.42 (PB6); also elsewhere on the board
SDA: U1.43 (PB7); also elsewhere on the board
STATUS: U1.39 (PB3); also elsewhere on the board
SWCLK: J3.4 (SWCLK), U1.37 (PA14)
SWDIO: J3.2 (SWDIO), U1.34 (PA13)
UART_RX: U1.13 (PA3); also elsewhere on the board
UART_TX: U1.12 (PA2); also elsewhere on the board
USB_DM: U1.32 (PA11); also elsewhere on the board
USB_DP: U1.33 (PA12); also elsewhere on the board
V3: C6.1, C7.1, C8.1, C9.1, C10.1, J3.1 (VTREF), R12.2, SW2.2 (B), U1.1 (VBAT), U1.9 (VDDA), U1.24 (VDD), U1.36 (VDDIO2), U1.48 (VDD); also elsewhere on the board
VBUS_SENSE: U1.10 (PA0); also elsewhere on the board
j3-7: J3.7 (KEY_NC)
j3-8: J3.8 (NC)
u1-2: U1.2 (PC13)
u1-6: U1.6 (PF1)


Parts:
D3: LTST-C191KGKT; LED_SMD__LED_0603_1608Metric; MPN LTST-C191KGKT
R14: 1000R; Resistor_SMD__R_0603_1608Metric; MPN RC0603FR-071KL

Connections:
GND: D3.1 (K); also elsewhere on the board
LED_A: D3.2 (A), R14.2
STATUS: R14.1; also elsewhere on the board



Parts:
C12: 10uF; Capacitor_SMD__C_0805_2012Metric; MPN GRM21BR61A106KE19L
C13, C15: 1uF; Capacitor_SMD__C_0603_1608Metric; MPN GRM188R71E105KA12D
C14: 100nF; Capacitor_SMD__C_0603_1608Metric; MPN GRM188R71H104KA93D
R15, R16, R20, R21: 10000R; Resistor_SMD__R_0603_1608Metric; MPN RT0603BRD0710KL
R17, R18: 4700R; Resistor_SMD__R_0603_1608Metric; MPN RC0603FR-074K7L
R19: 22R; Resistor_SMD__R_0603_1608Metric; MPN RC0603FR-0722RL
U4: REF3025AIDBZR; Package_TO_SOT_SMD__SOT-23; MPN REF3025AIDBZR

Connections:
ADC_DRDY_N: R15.1; also elsewhere on the board
ADC_RESET_N: R16.1; also elsewhere on the board
GND: C12.2, C13.2, C14.2, C15.2, R21.2, U4.3 (GND); also elsewhere on the board
REF_2V5: C13.1, R20.1, U4.2 (OUT); also elsewhere on the board
SCL: R18.1; also elsewhere on the board
SDA: R17.1; also elsewhere on the board
V3: R15.2, R16.2, R17.2, R18.2; also elsewhere on the board
VA: C12.1, C14.1, R19.2, U4.1 (IN); also elsewhere on the board
VA_SW: R19.1; also elsewhere on the board
VMID: C15.1, R20.2, R21.1; also elsewhere on the board



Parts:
C16, C17, C18: 100nF; Capacitor_SMD__C_0603_1608Metric; MPN GRM188R71H104KA93D
C19: 1uF; Capacitor_SMD__C_0603_1608Metric; MPN GRM188R71E105KA12D
R70: 10000R; Resistor_SMD__R_0603_1608Metric; MPN RT0603BRD0710KL
R71: 100000R; Resistor_SMD__R_0603_1608Metric; MPN RT0603BRD07100KL
U5: OPA387DBVR; Package_TO_SOT_SMD__SOT-23-5; MPN OPA387DBVR
U6: ADS122C04IPWR; Package_SO__TSSOP-16_4.4x5mm_P0.65mm; MPN ADS122C04IPWR

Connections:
ADC_DRDY_N: U6.14 (DRDY_N); also elsewhere on the board
ADC_RESET_N: U6.3 (RESET_N); also elsewhere on the board
CLAMP_GATE: R70.2, R71.1; also elsewhere on the board
GATE_SUPPLY: R70.1; also elsewhere on the board
GND: C16.2, C17.2, C18.2, C19.2, U5.2 (VSS), U6.1 (A0), U6.2 (A1), U6.4 (DGND), U6.5 (AVSS), U6.8 (REFN); also elsewhere on the board
H2S_AE_ADC: U6.6 (AIN3); also elsewhere on the board
H2S_WE_ADC: U6.7 (AIN2); also elsewhere on the board
REF_2V5: C19.1, U6.9 (REFP); also elsewhere on the board
SCL: U6.16 (SCL); also elsewhere on the board
SDA: U6.15 (SDA); also elsewhere on the board
SO2_AE_ADC: U6.10 (AIN1); also elsewhere on the board
SO2_WE_ADC: U6.11 (AIN0); also elsewhere on the board
V3: C18.1, U6.13 (DVDD); also elsewhere on the board
VA: C16.1, C17.1, U5.5 (VDD), U6.12 (AVDD); also elsewhere on the board
VMID: U5.3 (INP); also elsewhere on the board
VZERO: R71.2, U5.1 (OUT), U5.4 (INM); also elsewhere on the board

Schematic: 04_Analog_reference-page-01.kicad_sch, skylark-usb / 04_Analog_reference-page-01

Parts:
C73: 1uF; Capacitor_SMD__C_0603_1608Metric; MPN GRM188R71E105KA12D
C74: 10nF; Capacitor_SMD__C_0603_1608Metric; MPN GRM188R71H103KA01D
D4: BAT54LT1G; Package_TO_SOT_SMD__SOT-23; MPN BAT54LT1G
Q7: MMBT3904LT1G; Package_TO_SOT_SMD__SOT-23; MPN MMBT3904LT1G
R72: 100000R; Resistor_SMD__R_0603_1608Metric; MPN RT0603BRD07100KL
R73, R74: 10000R; Resistor_SMD__R_0603_1608Metric; MPN RT0603BRD0710KL
U13: TPS22918DBVR; Package_TO_SOT_SMD__SOT-23-6; MPN TPS22918DBVR

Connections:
2: D4.2 (S)
ANA_CT: C74.1, U13.4 (CT)
ANA_EN: R72.1, U13.3 (ON); also elsewhere on the board
CLAMP_BASE: Q7.1 (G), R74.2
CLAMP_GATE: Q7.3 (D); also elsewhere on the board
CLAMP_HOLD: R73.2, R74.1; also elsewhere on the board
GATE_SUPPLY: D4.3 (D); also elsewhere on the board
GND: C73.2, C74.2, R72.2, U13.2 (GND); also elsewhere on the board
USB_5V: D4.1 (G); also elsewhere on the board
V3: C73.1, R73.1, U13.1 (VIN); also elsewhere on the board
VA_SW: U13.5 (QOD), U13.6 (VOUT); also elsewhere on the board
VZERO: Q7.2 (S); also elsewhere on the board

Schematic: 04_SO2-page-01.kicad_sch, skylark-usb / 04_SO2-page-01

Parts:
C30, C33: 100nF; Capacitor_SMD__C_1206_3216Metric; MPN C3216C0G1H104JT000N
C31: 10uF; Capacitor_SMD__C_0805_2012Metric; MPN GRM21BR61A106KE19L
GS1: SGX-7SO2-AQ-20; SGX7_AQ_Socket; MPN SGX-7SO2-AQ-20
Q1: MMBFJ270; Package_TO_SOT_SMD__SOT-23; MPN MMBFJ270
R30, R33: 20R; Resistor_SMD__R_0603_1608Metric; MPN RT0603BRD0720RL
R31, R34: 100000R; Resistor_SMD__R_0603_1608Metric; MPN RT0603BRD07100KL
R32: 10000R; Resistor_SMD__R_0603_1608Metric; MPN RT0603BRD0710KL
U7: OPA2387DGKR; Package_SO__VSSOP-8_3x3mm_P0.65mm; MPN OPA2387DGKR
U8: OPA387DBVR; Package_TO_SOT_SMD__SOT-23-5; MPN OPA387DBVR

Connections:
CLAMP_GATE: Q1.3 (G); also elsewhere on the board
GND: C31.2, U7.4 (VSS), U8.2 (VSS); also elsewhere on the board
SO2_AE: GS1.AE (Auxiliary), R33.1; also elsewhere on the board
SO2_AE_OUT: C33.2, R34.2, U7.7 (OUT_B); also elsewhere on the board
SO2_AE_SUM: C33.1, R33.2, R34.1, U7.6 (INM_B)
SO2_CE: GS1.CE (Counter); also elsewhere on the board
SO2_CE_DRV: U8.1 (OUT); also elsewhere on the board
SO2_RE: GS1.RE (Reference), Q1.2 (S); also elsewhere on the board
SO2_RE_FB: U8.4 (INM); also elsewhere on the board
SO2_WE: GS1.WE (Working), Q1.1 (D), R30.1
SO2_WE_ADC: C31.1, R32.2; also elsewhere on the board
SO2_WE_OUT: C30.2, R31.2, R32.1, U7.1 (OUT_A)
SO2_WE_SUM: C30.1, R30.2, R31.1, U7.2 (INM_A)
VA: U7.8 (VDD), U8.5 (VDD); also elsewhere on the board
VZERO: U7.3 (INP_A), U7.5 (INP_B), U8.3 (INP); also elsewhere on the board

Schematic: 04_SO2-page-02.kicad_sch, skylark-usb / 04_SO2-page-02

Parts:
C34: 10uF; Capacitor_SMD__C_0805_2012Metric; MPN GRM21BR61A106KE19L
C36: 100nF; Capacitor_SMD__C_1206_3216Metric; MPN C3216C0G1H104JT000N
C37, C38: 100nF; Capacitor_SMD__C_0603_1608Metric; MPN GRM188R71H104KA93D
Q2: MMBFJ270; Package_TO_SOT_SMD__SOT-23; MPN MMBFJ270
R35, R36: 10000R; Resistor_SMD__R_0603_1608Metric; MPN RT0603BRD0710KL
R37, R75: 100R; Resistor_SMD__R_0603_1608Metric; MPN RC0603FR-07100RL

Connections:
CLAMP_GATE: Q2.3 (G); also elsewhere on the board
GND: C34.2, C37.2, C38.2; also elsewhere on the board
GUARD: R75.2
SO2_AE: Q2.1 (D); also elsewhere on the board
SO2_AE_ADC: C34.1, R35.2; also elsewhere on the board
SO2_AE_OUT: R35.1; also elsewhere on the board
SO2_CE: R37.2; also elsewhere on the board
SO2_CE_DRV: C36.1, R37.1; also elsewhere on the board
SO2_RE: Q2.2 (S), R36.1; also elsewhere on the board
SO2_RE_FB: C36.2, R36.2; also elsewhere on the board
VA: C37.1, C38.1; also elsewhere on the board
VZERO: R75.1; also elsewhere on the board

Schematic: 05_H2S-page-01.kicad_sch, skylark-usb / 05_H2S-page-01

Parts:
C50, C53: 100nF; Capacitor_SMD__C_1206_3216Metric; MPN C3216C0G1H104JT000N
C51: 10uF; Capacitor_SMD__C_0805_2012Metric; MPN GRM21BR61A106KE19L
GS2: SGX-7H2S-AQ-25; SGX7_AQ_Socket; MPN SGX-7H2S-AQ-25
Q3: MMBFJ270; Package_TO_SOT_SMD__SOT-23; MPN MMBFJ270
R50, R53: 20R; Resistor_SMD__R_0603_1608Metric; MPN RT0603BRD0720RL
R51, R54: 20000R; Resistor_SMD__R_0603_1608Metric; MPN RT0603BRD0720KL
R52: 10000R; Resistor_SMD__R_0603_1608Metric; MPN RT0603BRD0710KL
U9: OPA2387DGKR; Package_SO__VSSOP-8_3x3mm_P0.65mm; MPN OPA2387DGKR
U10: OPA387DBVR; Package_TO_SOT_SMD__SOT-23-5; MPN OPA387DBVR

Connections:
CLAMP_GATE: Q3.3 (G); also elsewhere on the board
GND: C51.2, U9.4 (VSS), U10.2 (VSS); also elsewhere on the board
H2S_AE: GS2.AE (Auxiliary), R53.1; also elsewhere on the board
H2S_AE_OUT: C53.2, R54.2, U9.7 (OUT_B); also elsewhere on the board
H2S_AE_SUM: C53.1, R53.2, R54.1, U9.6 (INM_B); also elsewhere on the board
H2S_CE: GS2.CE (Counter); also elsewhere on the board
H2S_CE_DRV: U10.1 (OUT); also elsewhere on the board
H2S_RE: GS2.RE (Reference), Q3.2 (S); also elsewhere on the board
H2S_RE_FB: U10.4 (INM); also elsewhere on the board
H2S_WE: GS2.WE (Working), Q3.1 (D), R50.1
H2S_WE_ADC: C51.1, R52.2; also elsewhere on the board
H2S_WE_OUT: C50.2, R51.2, R52.1, U9.1 (OUT_A); also elsewhere on the board
H2S_WE_SUM: C50.1, R50.2, R51.1, U9.2 (INM_A); also elsewhere on the board
VA: U9.8 (VDD), U10.5 (VDD); also elsewhere on the board
VZERO: U9.3 (INP_A), U9.5 (INP_B), U10.3 (INP); also elsewhere on the board

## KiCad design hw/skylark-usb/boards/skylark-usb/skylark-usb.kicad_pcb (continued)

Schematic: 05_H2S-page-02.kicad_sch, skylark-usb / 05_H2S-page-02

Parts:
C54: 10uF; Capacitor_SMD__C_0805_2012Metric; MPN GRM21BR61A106KE19L
C56, C80, C81, C82, C83: 100nF; Capacitor_SMD__C_1206_3216Metric; MPN C3216C0G1H104JT000N
C57, C58: 100nF; Capacitor_SMD__C_0603_1608Metric; MPN GRM188R71H104KA93D
Q4: MMBFJ270; Package_TO_SOT_SMD__SOT-23; MPN MMBFJ270
R55, R56: 10000R; Resistor_SMD__R_0603_1608Metric; MPN RT0603BRD0710KL
R57: 100R; Resistor_SMD__R_0603_1608Metric; MPN RC0603FR-07100RL

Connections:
CLAMP_GATE: Q4.3 (G); also elsewhere on the board
GND: C54.2, C57.2, C58.2; also elsewhere on the board
H2S_AE: Q4.1 (D); also elsewhere on the board
H2S_AE_ADC: C54.1, R55.2; also elsewhere on the board
H2S_AE_OUT: R55.1; also elsewhere on the board
H2S_CE: R57.2; also elsewhere on the board
H2S_CE_DRV: C56.1, R57.1; also elsewhere on the board
H2S_RE: Q4.2 (S), R56.1; also elsewhere on the board
H2S_RE_FB: C56.2, R56.2; also elsewhere on the board
H2S_WE_OUT: C80.2, C81.2, C82.2, C83.2; also elsewhere on the board
H2S_WE_SUM: C80.1, C81.1, C82.1, C83.1; also elsewhere on the board
VA: C57.1, C58.1; also elsewhere on the board

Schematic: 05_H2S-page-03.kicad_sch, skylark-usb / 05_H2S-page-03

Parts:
C84, C85, C86, C87: 100nF; Capacitor_SMD__C_1206_3216Metric; MPN C3216C0G1H104JT000N

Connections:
H2S_AE_OUT: C84.2, C85.2, C86.2, C87.2; also elsewhere on the board
H2S_AE_SUM: C84.1, C85.1, C86.1, C87.1; also elsewhere on the board

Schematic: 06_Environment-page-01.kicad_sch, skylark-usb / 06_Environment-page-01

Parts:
C70, C71, C72: 100nF; Capacitor_SMD__C_0603_1608Metric; MPN GRM188R71H104KA93D
U11: SHT40-AD1F-R2; SHT40; MPN SHT40-AD1F-R2
U12: BMP388; MPN BMP388

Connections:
GND: C70.2, C71.2, C72.2, U11.4 (VSS), U12.3 (GND), U12.5 (I2C_ADDR), U12.8 (GND), U12.9 (GND); also elsewhere on the board
SCL: U11.2 (SCL), U12.2 (SCL); also elsewhere on the board
SDA: U11.1 (SDA), U12.4 (SDA); also elsewhere on the board
V3: C70.1, C71.1, C72.1, U11.3 (VDD), U12.1 (VDDIO), U12.6 (CSB), U12.10 (VDD); also elsewhere on the board
u12-7: U12.7 (INT)

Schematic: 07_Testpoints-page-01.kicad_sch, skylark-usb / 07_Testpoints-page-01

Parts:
TP1, TP2, TP3, TP4, TP5, TP6, TP7: Test pad 1mm; TestPoint__TestPoint_Pad_D1.0mm; MPN Test pad 1mm

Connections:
GND: TP1.1; also elsewhere on the board
PM_5V: TP7.1; also elsewhere on the board
REF_2V5: TP5.1; also elsewhere on the board
USB_5V: TP2.1; also elsewhere on the board
V3: TP3.1; also elsewhere on the board
VA: TP4.1; also elsewhere on the board
VZERO: TP6.1; also elsewhere on the board



Board: 4 copper layers, 90.0 x 100.0 mm, 132 parts (38 on the bottom side), 66 nets.

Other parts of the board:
H1, H2, H3, H4: M3; MountingHole__MountingHole_3.2mm_M3

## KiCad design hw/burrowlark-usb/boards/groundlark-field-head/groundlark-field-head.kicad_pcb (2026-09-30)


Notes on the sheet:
Atopile-derived review schematic - prototype, not released. The Pi hosts acquisition and Coldfoot processing; the USB head has a local MCU. Global net labels connect functional sheets.



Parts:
C1: 2.2u; Capacitor_SMD__C_0805_2012Metric; MPN GRM21BR71E225KA73L
C2: 4.7u; Capacitor_SMD__C_0805_2012Metric; MPN GRM21BR71A475KA73L
D1, D2: USBLC6-2SC6; Package_TO_SOT_SMD__SOT-23-6; MPN USBLC6-2SC6
F1: 500mA PTC; Fuse__Fuse_1812_4532Metric; MPN MF-MSMF050-2
J1: USB-C DEVICE; Connector_USB__USB_C_Receptacle_GCT_USB4105-xx-A_16P_TopMnt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; MPN USB4105-GF-A
R1, R2: 5.1k; Resistor_SMD__R_0603_1608Metric; MPN RC0603FR-075K1L
U4: AP2112K-3.3; Package_TO_SOT_SMD__SOT-23-5; MPN AP2112K-3.3TRG1

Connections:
4: U4.4 (NC)
A8: J1.A8
B8: J1.B8
GND: C1.2, C2.2, D1.2, D2.2, J1.A1, J1.A12, J1.B1, J1.B12, J1.S1, R1.2, R2.2, U4.2 (GND); also elsewhere on the board
USB_5V: C1.1, F1.2, U4.1 (VIN), U4.3 (EN)
USB_CC1: D2.1, D2.6, J1.A5, R1.1
USB_CC2: D2.3, D2.4, J1.B5, R2.1
USB_DM: D1.3, D1.4, J1.A7, J1.B7; also elsewhere on the board
USB_DP: D1.1, D1.6, J1.A6, J1.B6; also elsewhere on the board
USB_VBUS: D1.5, D2.5, F1.1, J1.A4, J1.A9, J1.B4, J1.B9
V3: C2.1, U4.5 (VOUT); also elsewhere on the board



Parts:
C3, C6, C7, C8: 100n; Capacitor_SMD__C_0603_1608Metric; MPN GRM188R71H104KA93D
J2: SWD / 3V3 SENSE; Connector_PinHeader_2.54mm__PinHeader_1x05_P2.54mm_Vertical; MPN M20-9990545
J3: BOOT0 jumper; Connector_PinHeader_2.54mm__PinHeader_1x02_P2.54mm_Vertical; MPN EEPROM write enable
R3, R4: 10k; Resistor_SMD__R_0603_1608Metric; MPN RC0603FR-0710KL
U1: STM32F042K6T6; Package_QFP__LQFP-32_7x7mm_P0.8mm; MPN STM32F042K6T6

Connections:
2: U1.2 (PF0)
3: U1.3 (PF1)
7: U1.7 (PA1)
8: U1.8 (PA2)
9: U1.9 (PA3)
10: U1.10 (PA4)
11: U1.11 (PA5)
12: U1.12 (PA6)
13: U1.13 (PA7)
15: U1.15 (PB1)
18: U1.18 (PA8)
19: U1.19 (PA9)
20: U1.20 (PA10)
25: U1.25 (PA15)
26: U1.26 (PB3)
27: U1.27 (PB4)
28: U1.28 (PB5)
BOOT0: J3.2, R4.1, U1.31 (BOOT0)
GND: C3.2, C6.2, C7.2, C8.2, J2.3, R4.2, U1.16 (VSS), U1.32 (VSS); also elsewhere on the board
MAG_DRDY: U1.14 (PB0); also elsewhere on the board
NRST: C8.1, J2.5, R3.2, U1.4 (NRST)
SCL: U1.29 (I2C_SCL); also elsewhere on the board
SDA: U1.30 (I2C_SDA); also elsewhere on the board
SENSOR_EN: U1.6 (PA0); also elsewhere on the board
SWCLK: J2.4, U1.24 (SWCLK)
SWDIO: J2.2, U1.23 (SWDIO)
USB_DM: U1.21 (USB_DM); also elsewhere on the board
USB_DP: U1.22 (USB_DP); also elsewhere on the board
V3: C3.1, C6.1, C7.1, J2.1, J3.1, R3.1, U1.1 (VDD), U1.5 (VDDA), U1.17 (VDDIO2); also elsewhere on the board

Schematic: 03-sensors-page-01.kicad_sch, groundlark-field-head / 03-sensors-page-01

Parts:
C4, C9, C10: 100n; Capacitor_SMD__C_0603_1608Metric; MPN GRM188R71H104KA93D
R5: 100k; Resistor_SMD__R_0603_1608Metric; MPN RC0603FR-07100KL
R7, R8: 4.7k; Resistor_SMD__R_0603_1608Metric; MPN RC0603FR-074K7L
U2: RM3100 XYZ; Groundlark__PNI_14190_Module; MPN PNI 14190
U5: TPS22919; Package_TO_SOT_SMD__SOT-363_SC-70-6; MPN TPS22919DCKR
U6: SHT45; MPN SHT45-AD1B-R2

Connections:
6: U2.6 (NC)
GND: C4.2, C9.2, C10.2, R5.2, U2.2 (SA1), U2.4 (SA0), U2.7 (AVSS), U2.14 (DVSS), U5.2 (GND), U6.4 (VSS); also elsewhere on the board
MAG_DRDY: U2.5 (DRDY); also elsewhere on the board
SCL: R8.1, U2.1 (SCL), U6.2 (SCL); also elsewhere on the board
SDA: R7.1, U2.3 (SDA), U6.1 (SDA); also elsewhere on the board
SENSOR_EN: R5.1, U5.3 (ON); also elsewhere on the board
V3: C9.1, U5.1 (IN); also elsewhere on the board
V3_SENSOR: C4.1, C10.1, R7.2, R8.2, U2.10 (I2CEN), U2.12 (DVDD), U2.13 (AVDD), U5.5 (QOD), U5.6 (OUT), U6.3 (VDD)
u2-8: U2.8 (NC)
u2-9: U2.9 (NC)
u2-11: U2.11 (NC)
u5-4: U5.4 (NC)


Board: 4 copper layers, 70.0 x 45.0 mm, 31 parts (0 on the bottom side), 17 nets.

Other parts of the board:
H1, H2, H3, H4: M2.5 NPTH; MountingHole__MountingHole_2.7mm_M2.5

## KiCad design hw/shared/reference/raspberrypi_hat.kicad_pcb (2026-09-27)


Board: 4 copper layers, 65.0 x 56.0 mm, 18 parts (1 on the bottom side), 10 nets.

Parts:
H1, H2, H3, H4: 3mm_Mounting_Hole; NPTH_3mm_ID
J3: 40HAT; PinSocket_2x20_P2.54mm_Vertical
J6: CONN_02X02; PinHeader_2x02_P2.54mm_Vertical
J9: CONN_01X02; PinHeader_1x02_P2.54mm_Vertical
Q1: DMG2305UX; SOT-23
Q2: DMMT5401; SOT-23-6
R6, R8: 3.9K; R_0603_1608Metric_Pad0.84x1.00mm_HandSolder
R7, R9, R11: DNP; R_0603_1608Metric_Pad0.84x1.00mm_HandSolder
R23, R29: 10K; R_0603_1608Metric_Pad0.84x1.00mm_HandSolder
R24: 47K; R_0603_1608Metric_Pad0.84x1.00mm_HandSolder
U2: CAT24C32; SOIC-8_3.9x4.9mm_P1.27mm

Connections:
/ID_SC_EEPROM: J3.28, R8.2, U2.6
/ID_SD_EEPROM: J3.27, R6.2, U2.5
/P3V3: J6.1, R6.1, R7.2, R8.1, R29.1, U2.8
/P3V3_HAT: J3.1, J6.2, R7.1
/P5V: J6.3, Q1.3, Q2.6, R9.2
/P5V_HAT: J3.2, J3.4, J6.4, Q1.2, Q2.5, R9.1
GND: J3.6, J3.9, J3.14, J3.20, J3.25, J3.30, J3.34, J3.39, J9.1, R11.2, R23.2, R24.2, U2.1, U2.2, U2.3, U2.4
unnamed: J9.2, R11.1, R29.2, U2.7
unnamed: Q1.1, Q2.4, R24.1
unnamed: Q2.1, Q2.2, Q2.3, R23.1

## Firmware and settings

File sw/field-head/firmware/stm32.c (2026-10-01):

/* SPDX-License-Identifier: MIT */
#include "head.h"
#include "boot.h"
#include <libopencm3/cm3/cortex.h>
#include <libopencm3/cm3/systick.h>
#include <libopencm3/stm32/rcc.h>
#include <libopencm3/stm32/crs.h>
#include <libopencm3/stm32/gpio.h>
#include <libopencm3/stm32/i2c.h>
#include <libopencm3/stm32/flash.h>
#include <libopencm3/stm32/iwdg.h>
#include <libopencm3/stm32/syscfg.h>
#include <libopencm3/usb/usbd.h>
#include <libopencm3/usb/cdc.h>
#include <string.h>
#ifndef BH_USB_VID
#define BH_USB_VID 0x1209
#define BH_USB_PID 0x0001
#endif
static bh_state state;
static usbd_device *usb;
static volatile uint64_t milliseconds;
static bool configured,dtr,suspended,tx_busy,zlp_pending;
static uint16_t tx_offset;
void sys_tick_handler(void){milliseconds++;}
uint64_t bh_clock(void){uint32_t mask=cm_mask_interrupts(1);uint64_t t=milliseconds;cm_mask_interrupts(mask);return t;}
void bh_delay(uint32_t ms){uint64_t end=bh_clock()+ms;while(bh_clock()<end)if(usb)usbd_poll(usb);}
void bh_power(bool enabled){
    if(enabled){gpio_set(GPIOA,GPIO0);gpio_mode_setup(GPIOB,GPIO_MODE_AF,GPIO_PUPD_NONE,GPIO6|GPIO7);gpio_set_af(GPIOB,GPIO_AF1,GPIO6|GPIO7);gpio_set_output_options(GPIOB,GPIO_OTYPE_OD,GPIO_OSPEED_2MHZ,GPIO6|GPIO7);i2c_peripheral_enable(I2C1);}
    else{i2c_peripheral_disable(I2C1);gpio_mode_setup(GPIOB,GPIO_MODE_ANALOG,GPIO_PUPD_NONE,GPIO0|GPIO6|GPIO7);gpio_clear(GPIOA,GPIO0);}
}
static bool wait_flag(uint32_t flag,uint64_t end){
    for(unsigned spin=0;spin<100000;spin++){
        uint32_t flags=I2C_ISR(I2C1);
        if(flags&(I2C_ISR_NACKF|I2C_ISR_ARLO))return false;
        if(flags&I2C_ISR_BERR)I2C_ICR(I2C1)=I2C_ICR_BERRCF;
        if(flags&flag)return true;
        if(bh_clock()>=end)return false;
        if(usb)usbd_poll(usb);
    }return false;
}
bool bh_i2c(uint8_t addr,const uint8_t *w,size_t wn,uint8_t *r,size_t rn){
    if(wn>32||rn>32||(!wn&&!rn)||!state.powered)return false;
    uint64_t end=bh_clock()+5;bool ok=true;
    for(unsigned spin=0;i2c_busy(I2C1);spin++)if(spin>=100000||bh_clock()>=end){ok=false;break;}
    I2C_ICR(I2C1)=0x3f38;
    if(ok&&wn){I2C_CR2(I2C1)=((uint32_t)addr<<1)|((uint32_t)wn<<16)|I2C_CR2_START|(rn?0:I2C_CR2_AUTOEND);
        for(size_t i=0;i<wn&&ok;i++){ok=wait_flag(I2C_ISR_TXIS,end);if(ok)I2C_TXDR(I2C1)=w[i];}
        if(ok)ok=wait_flag(rn?I2C_ISR_TC:I2C_ISR_STOPF,end);}
    if(ok&&rn){I2C_CR2(I2C1)=((uint32_t)addr<<1)|((uint32_t)rn<<16)|I2C_CR2_RD_WRN|I2C_CR2_START|I2C_CR2_AUTOEND;
        for(size_t i=0;i<rn&&ok;i++){ok=wait_flag(I2C_ISR_RXNE,end);if(ok)r[i]=(uint8_t)I2C_RXDR(I2C1);}
        if(ok)ok=wait_flag(I2C_ISR_STOPF,end);}
    if(!ok){I2C_CR2(I2C1)|=I2C_CR2_STOP;i2c_peripheral_disable(I2C1);if(state.powered)i2c_peripheral_enable(I2C1);}
    I2C_ICR(I2C1)=0x3f38;return ok&&state.powered;
}
static const struct usb_device_descriptor device={
    .bLength=USB_DT_DEVICE_SIZE,.bDescriptorType=USB_DT_DEVICE,.bcdUSB=0x0200,
    .bDeviceClass=USB_CLASS_CDC,.bMaxPacketSize0=64,.idVendor=BH_USB_VID,
    .idProduct=BH_USB_PID,.bcdDevice=0x0100,.iManufacturer=1,.iProduct=2,.iSerialNumber=3,.bNumConfigurations=1};
static const struct usb_endpoint_descriptor comm_ep[]={
    {.bLength=USB_DT_ENDPOINT_SIZE,.bDescriptorType=USB_DT_ENDPOINT,.bEndpointAddress=0x83,.bmAttributes=USB_ENDPOINT_ATTR_INTERRUPT,.wMaxPacketSize=16,.bInterval=255}};
static const struct usb_endpoint_descriptor data_ep[]={
    {.bLength=USB_DT_ENDPOINT_SIZE,.bDescriptorType=USB_DT_ENDPOINT,.bEndpointAddress=0x01,.bmAttributes=USB_ENDPOINT_ATTR_BULK,.wMaxPacketSize=64},
    {.bLength=USB_DT_ENDPOINT_SIZE,.bDescriptorType=USB_DT_ENDPOINT,.bEndpointAddress=0x82,.bmAttributes=USB_ENDPOINT_ATTR_BULK,.wMaxPacketSize=64}};
static const struct {
    struct usb_cdc_header_descriptor header;
    struct usb_cdc_call_management_descriptor call;
    struct usb_cdc_acm_descriptor acm;
    struct usb_cdc_union_descriptor group;
} __attribute__((packed)) extra={
    {5,CS_INTERFACE,USB_CDC_TYPE_HEADER,0x0110},
    {5,CS_INTERFACE,USB_CDC_TYPE_CALL_MANAGEMENT,0,1},
    {4,CS_INTERFACE,USB_CDC_TYPE_ACM,2},
    {5,CS_INTERFACE,USB_CDC_TYPE_UNION,0,1}};
static const struct usb_interface_descriptor interfaces[]={
    {.bLength=USB_DT_INTERFACE_SIZE,.bDescriptorType=USB_DT_INTERFACE,.bInterfaceNumber=0,.bNumEndpoints=1,.bInterfaceClass=USB_CLASS_CDC,.bInterfaceSubClass=USB_CDC_SUBCLASS_ACM,.bInterfaceProtocol=USB_CDC_PROTOCOL_AT,.endpoint=comm_ep,.extra=&extra,.extralen=sizeof extra},
    {.bLength=USB_DT_INTERFACE_SIZE,.bDescriptorType=USB_DT_INTERFACE,.bInterfaceNumber=1,.bNumEndpoints=2,.bInterfaceClass=USB_CLASS_DATA,.endpoint=data_ep}};
static const struct usb_interface ifaces[]={{.num_altsetting=1,.altsetting=interfaces},{.num_altsetting=1,.altsetting=interfaces+1}};
static const struct usb_config_descriptor configuration={
    .bLength=USB_DT_CONFIGURATION_SIZE,.bDescriptorType=USB_DT_CONFIGURATION,.bNumInterfaces=2,.bConfigurationValue=1,.bmAttributes=0x80,.bMaxPower=50,.interface=ifaces};
static uint8_t control_buffer[128];
static struct usb_cdc_line_coding coding={115200,0,0,8};
static enum usbd_request_return_codes control(usbd_device *dev,struct usb_setup_data *req,uint8_t **buf,uint16_t *len,void (**complete)(usbd_device *,struct usb_setup_data *)) {
    (void)dev;(void)complete;
    if(req->wIndex!=0)return USBD_REQ_NOTSUPP;
    if(req->bRequest==USB_CDC_REQ_SET_CONTROL_LINE_STATE) { dtr=(req->wValue&1)!=0;return USBD_REQ_HANDLED; }
    if(req->bRequest==USB_CDC_REQ_GET_LINE_CODING) { *buf=(uint8_t *)&coding;*len=sizeof coding;return USBD_REQ_HANDLED; }
    if(req->bRequest==USB_CDC_REQ_SET_LINE_CODING && *len==sizeof coding) { memcpy(&coding,*buf,sizeof coding);return USBD_REQ_HANDLED; }
    return USBD_REQ_NOTSUPP;
}
static void receive(usbd_device *dev,uint8_t ep) { uint8_t ignored[64];usbd_ep_read_packet(dev,ep,ignored,sizeof ignored); }
static void transmitted(usbd_device *dev,uint8_t ep) { (void)dev;(void)ep;tx_busy=false; }
static void set_config(usbd_device *dev,uint16_t value) {
    configured=value==1;
    if(!configured)return;
    usbd_ep_setup(dev,0x01,USB_ENDPOINT_ATTR_BULK,64,receive);
    tx_busy=false;zlp_pending=false;
    usbd_ep_setup(dev,0x82,USB_ENDPOINT_ATTR_BULK,64,transmitted);
    usbd_ep_setup(dev,0x83,USB_ENDPOINT_ATTR_INTERRUPT,16,NULL);
    usbd_register_control_callback(dev,USB_REQ_TYPE_CLASS|USB_REQ_TYPE_INTERFACE,USB_REQ_TYPE_TYPE|USB_REQ_TYPE_RECIPIENT,control);
}
static void reset_usb(void) { configured=false;dtr=false;suspended=false;tx_busy=false;zlp_pending=false;tx_offset=0;bh_supply(&state,false,bh_clock()); }
static void suspend_usb(void) { suspended=true;tx_offset=0;bh_supply(&state,false,bh_clock()); }
static void resume_usb(void) { suspended=false; }

static void boot_erase(unsigned page){flash_erase_page(0x08007800+page*1024);}
static void boot_program(unsigned word,uint32_t value){flash_program_word(0x08007800+word*4,value);}
int main(void){
    rcc_clock_setup_in_hsi48_out_48mhz();rcc_set_usbclk_source(RCC_HSI48);
    rcc_periph_clock_enable(RCC_GPIOA);rcc_periph_clock_enable(RCC_GPIOB);
    gpio_mode_setup(GPIOA,GPIO_MODE_ANALOG,GPIO_PUPD_NONE,GPIO1|GPIO2|GPIO3|GPIO4|GPIO5|GPIO6|GPIO7|GPIO8|GPIO15);
    gpio_mode_setup(GPIOB,GPIO_MODE_ANALOG,GPIO_PUPD_NONE,GPIO0|GPIO1|GPIO3|GPIO4|GPIO5|GPIO6|GPIO7);
    gpio_clear(GPIOA,GPIO0);gpio_mode_setup(GPIOA,GPIO_MODE_OUTPUT,GPIO_PUPD_NONE,GPIO0);
    systick_set_clocksource(STK_CSR_CLKSOURCE_AHB);systick_set_reload(47999);systick_interrupt_enable();systick_counter_enable();
    rcc_periph_clock_enable(RCC_I2C1);rcc_set_i2c_clock_hsi(RCC_I2C1);rcc_osc_on(RCC_HSI);rcc_wait_for_osc_ready(RCC_HSI);
    i2c_set_speed(I2C1,i2c_speed_sm_100k,8);
    char serial[25];const uint8_t *uid=(const uint8_t *)0x1ffff7ac;static const char hex[]="0123456789abcdef";
    for(unsigned i=0;i<12;i++){serial[2*i]=hex[uid[i]>>4];serial[2*i+1]=hex[uid[i]&15];}serial[24]=0;
    flash_unlock();flash_clear_status_flags();uint32_t boot=sk_boot_next((const volatile uint32_t *)0x08007800,boot_erase,boot_program);flash_lock();
    bh_init(&state,serial,boot);
    const char *strings[]={"Groundlark","Burrowlark DAQUSB-01 prototype",serial};
    rcc_periph_clock_enable(RCC_CRS);crs_autotrim_usb_enable();rcc_periph_clock_enable(RCC_USB);rcc_periph_clock_enable(RCC_SYSCFG_COMP);
    /* STM32F042K6 pins 21/22: map USB PA11/12 onto PA9/10. RM0091 CFGR1 bit 4. */
    SYSCFG_CFGR1|=(1u<<4);
    gpio_mode_setup(GPIOA,GPIO_MODE_AF,GPIO_PUPD_NONE,GPIO9|GPIO10);gpio_set_af(GPIOA,GPIO_AF2,GPIO9|GPIO10);
    usb=usbd_init(&st_usbfs_v2_usb_driver,&device,&configuration,strings,3,control_buffer,sizeof control_buffer);
    usbd_register_set_config_callback(usb,set_config);usbd_register_reset_callback(usb,reset_usb);usbd_register_suspend_callback(usb,suspend_usb);usbd_register_resume_callback(usb,resume_usb);
    iwdg_set_period_ms(2000);iwdg_start();
    for(;;){
        usbd_poll(usb);bh_supply(&state,configured&&!suspended,bh_clock());
        bool connected=configured&&!suspended&&dtr;
        if(connected!=state.connected){tx_offset=0;bh_connection(&state,connected);}
        bh_tick(&state,bh_clock());
        uint16_t len;const uint8_t *frame=bh_tx(&state,&len);
        if(connected&&!tx_busy&&zlp_pending){tx_busy=true;zlp_pending=false;usbd_ep_write_packet(usb,0x82,NULL,0);}
        else if(frame&&connected&&!tx_busy){unsigned remain=len-tx_offset,n=remain>64?64:remain;int sent=usbd_ep_write_packet(usb,0x82,frame+tx_offset,n);
            if(sent>0){tx_busy=true;tx_offset+=(uint16_t)sent;if(tx_offset==len){bh_tx_done(&state);tx_offset=0;zlp_pending=sent==64;}}}
        iwdg_reset();__asm__("wfi");
    }
}

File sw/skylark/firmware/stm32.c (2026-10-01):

/* SPDX-License-Identifier: MIT
 * Skylark Rev A, STM32F072CBT6. USB and peripheral registers via libopencm3.
 */
#include "platform.h"
#include "boot.h"
#include "peripherals.h"
#include <libopencm3/cm3/cortex.h>
#include <libopencm3/cm3/nvic.h>
#include <libopencm3/cm3/systick.h>
#include <libopencm3/stm32/rcc.h>
#include <libopencm3/stm32/crs.h>
#include <libopencm3/stm32/gpio.h>
#include <libopencm3/stm32/i2c.h>
#include <libopencm3/stm32/usart.h>
#include <libopencm3/stm32/adc.h>
#include <libopencm3/stm32/flash.h>
#include <libopencm3/stm32/iwdg.h>
#include <libopencm3/usb/usbd.h>
#include <libopencm3/usb/cdc.h>
#include <string.h>

/* pid.codes 1209:0001 is exclusively for private testing. Production builds
 * must override both IDs with an allocated pair. See README. */
#ifndef SK_USB_VID
#define SK_USB_VID 0x1209
#define SK_USB_PID 0x0001
#endif
static sk_state state;
static usbd_device *usb;
static volatile uint64_t milliseconds;
static bool configured,dtr,suspended;
static uint16_t tx_offset;
static bool tx_busy,zlp_pending,slow_clock;
static volatile uint8_t rx[256],rx_head,rx_tail;
static volatile bool rx_error;
/* Keep the polled USB peripheral above ES0223's 10 MHz APB minimum, even
 * while servicing resume/reset. APB is undivided relative to AHB here. */
#define SK_SUSPEND_HZ 12000000u
_Static_assert(SK_SUSPEND_HZ>=10000000u,"USB APB minimum");
_Static_assert(ADC_CR_ADEN==1 && ADC_CR_ADCAL==(1u<<31) && ADC_CR_ADSTP==16 &&
               ADC_ISR_EOC==4 && ADC_ISR_OVR==16 && I2C_ISR_BERR==256 &&
               I2C_ISR_NACKF==16 && I2C_ISR_ARLO==512,"MMIO fixture bit definitions");
uint32_t sk_register_read(sk_register reg) {
    switch(reg) {
    case SK_ADC_CR:return ADC_CR(ADC1);
    case SK_ADC_ISR:return ADC_ISR(ADC1);
    case SK_ADC_CHSELR:return ADC_CHSELR(ADC1);
    case SK_ADC_DR:return ADC_DR(ADC1);
    case SK_I2C_ISR:return I2C_ISR(I2C1);
    case SK_I2C_ICR:return 0;
    }return 0;
}
void sk_register_write(sk_register reg,uint32_t value) {
    switch(reg) {
    case SK_ADC_CR:ADC_CR(ADC1)=value;break;
    case SK_ADC_ISR:ADC_ISR(ADC1)=value;break;
    case SK_ADC_CHSELR:ADC_CHSELR(ADC1)=value;break;
    case SK_I2C_ICR:I2C_ICR(I2C1)=value;break;
    default:break;
    }
}
void sys_tick_handler(void) { milliseconds++; }
uint64_t sk_clock(void) { uint32_t mask=cm_mask_interrupts(1);uint64_t t=milliseconds;cm_mask_interrupts(mask);return t; }
static void service(void) {
    if(usb)usbd_poll(usb);
    if(rx_error) { rx_error=false;rx_tail=rx_head;sk_uart_error(); }
    for(unsigned n=0;n<64 && rx_tail!=rx_head;n++) { uint8_t b=rx[rx_tail++];sk_uart_input(b); }
}
void sk_delay(uint32_t ms) { uint64_t end=sk_clock()+ms;while(sk_clock()<end)service(); }
void sk_clamp(bool hold) { if(hold || !state.powered)gpio_set(GPIOB,GPIO13);else gpio_clear(GPIOB,GPIO13); }
static void pm_off(void) {
    gpio_clear(GPIOA,GPIO4);gpio_set(GPIOA,GPIO6|GPIO7);
    gpio_mode_setup(GPIOA,GPIO_MODE_INPUT,GPIO_PUPD_NONE,GPIO2);
}
void sk_rails(bool enabled) {
    if(enabled) {
        gpio_set(GPIOB,GPIO12|GPIO1);
        if(sk_pm_supply_ok()) {
            gpio_clear(GPIOA,GPIO6|GPIO7);gpio_set(GPIOA,GPIO4);
            gpio_mode_setup(GPIOA,GPIO_MODE_AF,GPIO_PUPD_NONE,GPIO2);
        }
    } else {
        /* Caller has already engaged WE/AE-to-RE clamps. */
        gpio_clear(GPIOB,GPIO1); /* Hold ADS122C04 reset before removing AVDD. */
        gpio_clear(GPIOB,GPIO12|GPIO3);pm_off();
    }
}
static bool i2c_wait(uint32_t flag,uint64_t end) {
    return sk_i2c_wait_flag(flag,end);
}
bool sk_i2c(uint8_t addr,const uint8_t *w,size_t wn,uint8_t *r,size_t rn) {
    if(wn>32 || rn>32 || (!wn && !rn))return false;
    uint64_t end=sk_clock()+5;bool ok=true;
    while(i2c_busy(I2C1))if(sk_clock()>=end) { ok=false;break; }
    I2C_ICR(I2C1)=0x3f38;
    if(ok && wn) {
        I2C_CR2(I2C1)=((uint32_t)addr<<1)|((uint32_t)wn<<16)|I2C_CR2_START|(rn?0:I2C_CR2_AUTOEND);
        for(size_t i=0;i<wn && ok;i++) { ok=i2c_wait(I2C_ISR_TXIS,end);if(ok)I2C_TXDR(I2C1)=w[i]; }
        if(ok)ok=i2c_wait(rn?I2C_ISR_TC:I2C_ISR_STOPF,end);
    }
    if(ok && rn) {
        I2C_CR2(I2C1)=((uint32_t)addr<<1)|((uint32_t)rn<<16)|I2C_CR2_RD_WRN|I2C_CR2_START|I2C_CR2_AUTOEND;
        for(size_t i=0;i<rn && ok;i++) { ok=i2c_wait(I2C_ISR_RXNE,end);if(ok)r[i]=(uint8_t)I2C_RXDR(I2C1); }
        if(ok)ok=i2c_wait(I2C_ISR_STOPF,end);
    }
    if(!ok) { I2C_CR2(I2C1)|=I2C_CR2_STOP;i2c_peripheral_disable(I2C1);i2c_peripheral_enable(I2C1); }
    I2C_ICR(I2C1)=0x3f38;return ok;
}
bool sk_pm_supply_ok(void) {
    unsigned raw=sk_adc_sample(0),ref=sk_adc_sample(17),cal=*(const uint16_t *)0x1ffff7ba;
    bool ok=ref && cal && gpio_get(GPIOA,GPIO5) && ((uint64_t)raw*6600*cal >= (uint64_t)4650*4095*ref);
    if(!ok)pm_off();
    return ok;
}
void usart2_isr(void) {
    uint32_t status=USART_ISR(USART2);
    if(status&(USART_ISR_ORE|USART_ISR_FE|USART_ISR_NF|USART_ISR_PE)) { USART_ICR(USART2)=15;rx_error=true; }
    if(status&USART_ISR_RXNE) {
        uint8_t b=(uint8_t)USART_RDR(USART2),next=(uint8_t)(rx_head+1);
        if(next==rx_tail)rx_error=true;else { rx[rx_head]=b;rx_head=next; }
    }
}
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

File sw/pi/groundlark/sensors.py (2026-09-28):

"""Small polling drivers with injected buses; manufacturer references in docs."""
from dataclasses import dataclass
from collections import deque
import struct
import time


class NotReady(OSError):
    pass


class DataGap(OSError):
    """Communication succeeded, but conversion continuity was lost.

    Emit a missing marker and unknown loss without resetting a healthy device.
    """


@dataclass
class Reading:
    raw: dict
    quality: int = 1
    acquisition_ns: int | None = None


class LSM6DSO:
    PERIODS = {38461538: 2, 19230769: 3, 9615385: 4, 4807692: 5}

    def __init__(self, bus, sleep=time.sleep, clock=time.monotonic):
        self.bus, self.sleep, self.clock = bus, sleep, clock

    def reg(self, address, count=1):
        data = self.bus.transfer(bytes([address | 0x80]) + bytes(count), mode=0, hz=1_000_000)
        if len(data) != count + 1: raise OSError("short IMU read")
        return data[1:]

    def write(self, address, value):
        self.bus.transfer(bytes([address, value]), mode=0, hz=1_000_000)

    def configure(self, cfg):
        if cfg["period_ns"] not in self.PERIODS: raise ValueError("IMU supports this driver's 26/52/104/208 Hz profiles only")
        if self.reg(0x0f) != b"\x6c": raise OSError("LSM6DSO identity mismatch")
        self.write(0x12, 1)
        for _ in range(100):
            if not self.reg(0x12)[0] & 1: break
            self.sleep(.001)
        else: raise TimeoutError("IMU reset timeout")
        odr = self.PERIODS[cfg["period_ns"]] << 4
        accel = {2: 0, 4: 8, 8: 12, 16: 4}[cfg["acceleration_range_g"]]
        gyro = {125: 2, 250: 0, 500: 4, 1000: 8, 2000: 12}[cfg["angular_rate_range_dps"]]
        # AN5192 UI path: high performance, accelerometer LPF1 only; gyro
        # LPF2, LPF1 bypassed, high-pass disabled. Record filter state as well
        # as ODR so a recording describes its actual bandwidth.
        settings = {0x10: odr | accel, 0x11: odr | gyro, 0x12: 0x44,
                    0x13: 0, 0x15: 0, 0x16: 0, 0x17: 0}
        for address in (0x12, 0x13, 0x15, 0x16, 0x17, 0x10, 0x11): self.write(address, settings[address])
        for address, value in settings.items():
            if self.reg(address)[0] != value: raise OSError("IMU configuration readback mismatch")
        self.sleep(.1)
        return dict(cfg, register_config=b"".join(bytes([r, v]) for r, v in sorted(settings.items())))

    def read(self):
        if self.reg(0x1e)[0] & 3 != 3: raise NotReady("IMU data not ready")
        values = struct.unpack("<7h", self.reg(0x20, 14))
        return Reading(dict(temperature=values[0], angular_rate=values[1:4], acceleration=values[4:7]),
                       3 if any(v in (-32768, 32767) for v in values[1:]) else 1)


def scl_crc(data):
    crc = 255
    for byte in data:
        crc ^= byte
        for _ in range(8): crc = ((crc << 1) ^ (0x1d if crc & 128 else 0)) & 255
    return crc ^ 255


def scl_command(opcode, value=0):
    data = bytes([opcode]) + value.to_bytes(2, "big")
    return data + bytes([scl_crc(data)])


class SCL3300:
    def __init__(self, bus, sleep=time.sleep):
        self.bus, self.sleep = bus, sleep

    def transfer(self, frame):
        self.sleep(.00002)  # CS high >=10 us; scheduler oversleep is safe.
        data = self.bus.transfer(frame, mode=0, hz=1_000_000)
        if len(data) != 4: raise OSError("short SCL3300 transfer")
        return data

    @staticmethod
    def response(data, opcode):
        if scl_crc(data[:3]) != data[3]: raise OSError("SCL3300 CRC mismatch")
        if data[0] & 0xfc != opcode: raise OSError("SCL3300 off-frame address mismatch")
        return int.from_bytes(data[1:3], "big"), data[0] & 3

    def reg(self, address):
        frame = scl_command(address << 2)
        self.transfer(frame)
        return self.response(self.transfer(frame), address << 2)

    def configure(self, cfg):
        mode = cfg["tilt_mode"]
        if mode not in (1, 2, 3, 4) or cfg["period_ns"] < 10_000_000: raise ValueError("SCL3300 polling profile")
        self.transfer(scl_command(0xb4, 0))
        self.sleep(.003)
        self.transfer(scl_command(0xb4, 0x20))
        self.sleep(.003)
        self.transfer(scl_command(0xb4, mode - 1))
        self.transfer(scl_command(0xb0, 0x1f))
        self.sleep({1: .025, 2: .015, 3: .100, 4: .100}[mode])
        frame = scl_command(0x18)
        self.transfer(frame)
        self.transfer(frame)
        _, rs = self.response(self.transfer(frame), 0x18)
        if rs != 1: raise OSError("SCL3300 startup flags did not clear")
        who, rs = self.reg(0x10)
        actual, mode_rs = self.reg(0x0d)
        if who != 0xc1 or rs != 1 or mode_rs != 1 or actual & 3 != mode - 1:
            raise OSError("SCL3300 identity/mode readback mismatch")
        return cfg

    def read(self):
        values, statuses = [], []
        for address in (1, 2, 3, 9, 10, 11, 5, 6):
            value, rs = self.reg(address)
            values.append(value)
            statuses.append(rs)
        signed = [v - 65536 if v & 32768 else v for v in values[:-1]]
        summary = values[-1]
        quality = 1 if not summary and all(s == 1 for s in statuses) else 4
        if summary == 0x40 and all(s in (1, 3) for s in statuses): quality = 3
        return Reading(dict(acceleration=signed[:3], angle=signed[3:6], temperature=signed[6], device_status=summary), quality)


def ubx_packet(cls, ident, payload):
    data = bytes([cls, ident]) + len(payload).to_bytes(2, "little") + payload
    a = b = 0
    for byte in data:
        a = (a + byte) & 255
        b = (b + a) & 255
    return b"\xb5\x62" + data + bytes([a, b])


class UBXParser:
    def __init__(self):
        self.buffer = bytearray()
        self.errors = 0

    def feed(self, data):
        if len(data) > 256: raise ValueError("UBX input chunk limit")
        self.buffer.extend(data)
        while True:
            start = self.buffer.find(b"\xb5\x62")
            if start < 0:
                self.buffer[:] = self.buffer[-1:] if self.buffer.endswith(b"\xb5") else b""
                return
            del self.buffer[:start]
            if len(self.buffer) < 6: return
            size = int.from_bytes(self.buffer[4:6], "little")
            if size > 1024:
                self.errors += 1
                del self.buffer[0]
                continue
            if len(self.buffer) < size + 8: return
            cls, ident = self.buffer[2:4]
            payload = bytes(self.buffer[6:6 + size])
            if bytes(self.buffer[:size + 8]) != ubx_packet(cls, ident, payload):
                self.errors += 1
                del self.buffer[0]
                continue
            del self.buffer[:size + 8]
            yield cls, ident, payload
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

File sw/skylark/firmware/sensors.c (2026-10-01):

/* SPDX-License-Identifier: MIT
 * TI ADS122C04 SBAS751B, Sensirion SHT4x, Bosch BMP388 and PMS5003 v2.3.
 * Raw transport bytes and factory trim are preserved; no gas calibration here.
 */
#include "platform.h"
#include <string.h>
static uint8_t mux, adc_counter, trim[21], pm_work[32], pm_frame[32], pm_n;
static bool adc_seen, pm_new, powered, climate_pending;
static uint64_t pm_time, adc_time, climate_due;
static bool command(uint8_t addr,uint8_t cmd,uint8_t *r,size_t n) { return sk_i2c(addr,&cmd,1,r,n); }
static bool write_reg(uint8_t addr,uint8_t reg,uint8_t value) { uint8_t w[]={reg,value};return sk_i2c(addr,w,2,NULL,0); }
static bool adc_reg(uint8_t reg,uint8_t expected) {
    uint8_t r[2];return command(0x40,(uint8_t)(0x20|(reg<<2)),r,2) && (r[0]^r[1])==255 && (r[0] & (reg==2?127:255))==expected;
}
static bool start_adc(uint8_t channel) {
    uint8_t value=(uint8_t)(((8+channel)<<4)|1);
    return write_reg(0x40,0x40,value) && adc_reg(0,value) && command(0x40,8,NULL,0);
}
void sk_power(bool enabled) {
    powered=enabled;sk_clamp(true);sk_rails(enabled);pm_n=0;pm_new=false;adc_seen=false;
    climate_pending=false;
}
uint8_t sk_configure(void) {
    uint8_t enabled=0,r[21];mux=0;adc_seen=false;
    bool adc=command(0x40,6,NULL,0);sk_delay(2);
    if(!powered)return 0;
    for(unsigned i=0;i<4 && adc;i++) adc=command(0x40,(uint8_t)(0x20|(i<<2)),r,1) && r[0]==0;
    adc=adc && write_reg(0x40,0x40,0x81) && write_reg(0x40,0x44,SK_ADC_CONFIG1) && write_reg(0x40,0x4c,0) && write_reg(0x40,0x48,0x50);
    adc=adc && adc_reg(0,0x81) && adc_reg(1,SK_ADC_CONFIG1) && adc_reg(2,0x50) && adc_reg(3,0);
    if(adc && start_adc(0))enabled|=15;
    /* Rails/reference have already had 150 ms to rise. Cell settling continues
     * for 60 s as MISSING; this duration is a prototype policy to qualify. */
    sk_clamp(false);
    if(command(0x44,0x89,NULL,0)) {
        sk_delay(2);
        if(!powered)return 0;
        if(sk_i2c(0x44,NULL,0,r,6) && sk_crc8(r,2)==r[2] && sk_crc8(r+3,2)==r[5])enabled|=32;
    }
    if(write_reg(0x76,0x7e,0xb6)) {
        sk_delay(3);
        if(!powered)return 0;
        bool ok=command(0x76,0,r,1) && r[0]==0x50 && command(0x76,0x31,trim,21);
        ok=ok && write_reg(0x76,0x1c,0x0b) && write_reg(0x76,0x1d,0x06) && write_reg(0x76,0x1b,0x33);
        ok=ok && command(0x76,0x1b,r,3) && r[0]==0x33 && r[1]==0x0b && r[2]==0x06;
        if(ok && command(0x76,2,r,1) && !(r[0]&7)) enabled|=64;
    }
    if(sk_pm_supply_ok())enabled|=16; /* UART configured at 9600 8N1; readiness is frame-based. */
    return enabled;
}
void sk_uart_error(void) { pm_n=0;pm_new=false; }
void sk_uart_input(uint8_t byte) {
    if(pm_n==0 && byte!=0x42)return;
    if(pm_n==1 && byte!=0x4d) { pm_n=byte==0x42?1:0;return; }
    pm_work[pm_n++]=byte;
    if(pm_n==4 && (pm_work[2]!=0 || pm_work[3]!=28)) { pm_n=0;return; }
    if(pm_n==32) {
        if(sk_pms_valid(pm_work)) { memcpy(pm_frame,pm_work,32);pm_new=true;pm_time=sk_clock(); }
        else pm_new=false;
        pm_n=0;
    }
}
uint8_t sk_read(uint8_t sid,sk_raw *raw) {
    if(sid<14) {
        if(sid!=10+mux)return 2;
        uint8_t d[8],r[2];uint8_t result=4;
        if(command(0x40,0x28,r,2) && (r[0]^r[1])==255) {
            if(!(r[0]&128))result=2;
            else if(command(0x40,0x10,d,8)) {
                bool ok=true;for(unsigned i=0;i<4;i++)if((d[i]^d[i+4])!=255)ok=false;
                if(ok) {
                    raw->counter=d[0];uint32_t v=(uint32_t)d[1]<<16|(uint32_t)d[2]<<8|d[3];
                    raw->counts=(v&0x800000)?(int32_t)(v|0xff000000u):(int32_t)v;
                    result=(raw->counts==8388607 || raw->counts==-8388608)?3:1;
                    if(adc_seen && ((uint8_t)(d[0]-adc_counter)!=1 || sk_clock()-adc_time>=10000))result=2;
                    adc_counter=d[0];adc_time=sk_clock();adc_seen=true;
                }
            }
        }
        mux=(mux+1)%4;if(!start_adc(mux))result=4;
        return result;
    }
    if(sid==14) {
        if(!sk_pm_supply_ok()) { pm_new=false;return 4; }
        if(!pm_new || sk_clock()-pm_time>1500)return 2;
        pm_new=false;memcpy(raw->data,pm_frame,32);return pm_frame[29]?4:1;
    }
    if(sid==15) {
        if(!powered)return 2;
        if(!climate_pending) {
            if(!command(0x44,0xfd,NULL,0))return 4;
            climate_due=sk_clock()+10;climate_pending=true;return 0;
        }
        if(sk_clock()<climate_due)return 0;
        climate_pending=false;
        if(sk_clock()-climate_due>=1000)return 2;
        if(!sk_i2c(0x44,NULL,0,raw->data,6) || sk_crc8(raw->data,2)!=raw->data[2] || sk_crc8(raw->data+3,2)!=raw->data[5])return 4;
        return 1;
    }
    uint8_t status;
    if(!command(0x76,3,&status,1))return 4;
    if((status&0x60)!=0x60)return 2;
    if(!command(0x76,4,raw->data,6))return 4;
    memcpy(raw->trim,trim,21);return 1;
}

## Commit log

2026-09-26 docs: name USB sensor board Burrowlark DAQUSB-01
2026-09-27 Organize hardware by product and document the board family
    [01-host-power-page-01.kicad_sch, 01-usb-power-page-01.kicad_sch, 02-controller-page-01.kicad_sch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]
2026-09-27 Add Skylark platform and board-family README render
    [01_USB_power-page-01.kicad_sch, 01_USB_power-page-02.kicad_sch, 01_USB_power-page-03.kicad_sch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]
2026-09-27 Harden Skylark signal chain and add manufacturing audit
    [03_ADC_reference-page-02.kicad_sch, 04_Analog_reference-page-01.kicad_sch, 04_SO2-page-01.kicad_sch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]
2026-09-28 Harden Groundlark and Skylark acquisition, power checks and assembly
    [assembly-bom.csv, groundlark-daqhat-01.dsn, groundlark-daqhat-01.kicad_pcb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]
2026-09-28 Add DAQHAT-01 prototype enclosure with recessed bird mark
2026-09-28 Use horizontal geophone connector and publish detailed enclosure render
    Synchronize J90 routing, native SES, assembly mapping, enclosure fit, models and validation. Add a 4K clear-PETG README render and derive assembly PDF part identities from package procurement. Preserve Git-normalized source bindings and original validation/render input hashes. Generated JLCPCB packages remain local.
    [03-geophone-page-01.kicad_sch, assembly-bom.csv, bom.csv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]
2026-09-28 Fix enclosure handedness and render detailed component models
    Audit Pi and Trenz pin orientation, correct R2 port geometry, add mirrored-geometry fault tests, and replace the README render with attributed detailed Pi component CAD.
    Validation: staged snapshot passes 176 hardware tests, 14 enclosure tests, and repository checks. PCB and SES inputs remain unchanged.
    [case.py, lab.py, render.py]
2026-09-30 Remove Burrowlark infrasound hardware and refresh board previews
    Keep DAQUSB-01 magnetometer-only across the circuit, routed PCB, BOM, review schematic and native routing snapshot. Publish the refreshed render in the main README and add population regression check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
    Validation: 125 pin checks, clean ERC/DRC, native routing replay, 3 Burrowlark regression tests and lab unit tests pass. Full lab builds pass; hardware regressions stop on unrelated DAQHAT-01 assembl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
    [01-usb-power-page-01.kicad_sch, 02-controller-page-01.kicad_sch, 03-sensors-page-01.kicad_sch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]
2026-09-30 Add TI Pi power supervision and expand DAQHAT enclosure
    [01-host-power-page-01.kicad_sch, 02-motion-array-page-01.kicad_sch, 03-geophone-page-01.kicad_sch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]
2026-09-30 Add SHT45 enclosure climate sensing to Burrowlark
    Add Sensirion SHT45-AD1B-R2 U6 and switched-rail bypass C10, with JLCPCB C5221601 stock evidence. Synchronize circuit, routed PCB, native SES, schematic, BOM, README render and browser model.
    Publish CRC-checked raw climate sensor 17 through simulation, recording and replay. Add enclosure controls, independent fault/recovery checks and protocol fixtures. The isolated software profile passes 213 tests; Burrowlark DRC/ERC and copper replay pass. Full hardware regression remains blocked by pre-existing assembly registry mismatches. MCU firmware and physical qualification remain pending.
    [03-sensors-page-01.kicad_sch, bom.csv, field_head.kicad_pcb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]
2026-09-30 Add Burrowlark favicon and revision silkscreen
    Place the shared favicon above the Burrowlark name and DAQUSB-01 / REV A2 label. Preserve the existing A2 revision and all 579 tracks/vias; author the artwork in placement metadata and retain it on a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
    Refresh README render, board previews and browser model/provenance. Native DRC/ERC, copper replay, repository structure, lab unit tests and workbench HTTP/browser checks pass.
    [groundlark-field-head.kicad_pcb]
2026-09-30 Add Groundlark GNSS timing, SMA access and calibration workflow
    [01-host-power-page-01.kicad_sch, 03-geophone-page-02.kicad_sch, 04-gnss-page-01.kicad_sch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]
2026-09-30 Finalize Skylark signal-chain updates and remove obsolete artifacts
    [01_USB_power-page-01.kicad_sch, 04_SO2-page-01.kicad_sch, 04_SO2-page-02.kicad_sch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]
2026-09-30 Fix Groundlark power and GNSS electrical faults
    [04-gnss-page-01.kicad_sch, 04-gnss-page-02.kicad_sch, 06-supply-isolation-page-02.kicad_sch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]
2026-09-30 Update Groundlark simulation and tests for revised hardware
2026-10-01 Harden station acquisition, firmware and local deployment
    Add continuous capture, bounded storage and recovery, authenticated local station UI, prototype Burrowlark and supervisor firmware, and Pi deployment services. Add autonomous geophone DRDY capture and fix continuous simulation beyond one hour. Validation: 283 software tests, three MCU ARM builds, FPGA checks and lab unit checks passed. The 168-hour soak and physical qualification remain pending.
    [supervisor-boot.cfg]
2026-10-01 Remove retired ASIC HAT variant and references
    [01-host-power-page-01.kicad_sch, 02-motion-array-page-01.kicad_sch, 02-motion-array-page-02.kicad_sch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]
